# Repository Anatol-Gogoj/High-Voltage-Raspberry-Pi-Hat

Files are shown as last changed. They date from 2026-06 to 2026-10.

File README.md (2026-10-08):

# High Voltage Raspberry Pi Hat
A high voltage Raspberry Pi hat dedicated to controlling and powering Dielectric Elastomer Actuators (DEAs) through a dedicated circuit without the risk of burning out expensive high voltage equipment.

Two channels, up to 5 kV into loads under 1 nF, with independent charge, hold and active
discharge per channel and a passive 1 GOhm bleeder across each output. Rev B fits the standard
65 x 56 mm HAT outline with the HV section potted. KiCad 10 project in
[`HV Pi Hat/`](HV%20Pi%20Hat/); design decisions are in
[`HV Pi Hat/docs/adr/`](HV%20Pi%20Hat/docs/adr/).

**Safety:** this board generates 5 kV. It has not been fabricated or reviewed by a qualified
electrical engineer, and the HV spacing basis is still open (ADR-0003). Do not build or energize
it from this repository as it stands.

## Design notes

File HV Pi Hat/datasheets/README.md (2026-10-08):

# Datasheets — HV Pi Hat

Local copies of datasheets for the key parts in this design. Pulled 2026-06-05.

| Part | Ref(s) | Role | Key specs | File | Source |
|---|---|---|---|---|---|
| HVM SMHV0550 | U1 | 5 kV programmable HV DC-DC module | 0–5 kV out, **200 µA** max, 5 V in (<350 mA), Program 0–5 V, Vmon/Imon 0–1 V, Ilimit (tie 5 V to disable), non-isolated (HVRTN=GND), 45–80 kHz | `HVM_SMHV_series.pdf` | [hvmtech.com/smhv-series](https://www.hvmtech.com/smhv-series) |
| HVM OPTO-100-05 | OR1–OR4 | HV opto-coupler (charge path / HV switch) | **10 kV** standoff, **CTR 0.15%**, LED Vf 2.9–3.25 V, LED 400 mA max, turn-on/off 2 µs, internal current-limit R | `HVM_OPTO-100.pdf` | [hvmtech.com/opto100](https://www.hvmtech.com/opto100) |
| Murata MHR0317SA107F70 | R1, R2 | HV bleeder / discharge resistor | **100 MΩ** (code 107), 0317 size, axial HV chip | `Murata_MHR0317SA_series.pdf` | [murata.com](https://www.murata.com/en-us/products/resistor/highvoltage) |
| Microchip TN0610N3-G | Q1–Q4 | N-MOSFET — opto-LED low-side driver | 100 V, 500 mA, Vgs(th) ≤ 2 V, TO-92 | `TN0610N3-G_Microchip.pdf` | [microchip.com/TN0610](https://www.microchip.com/en-us/product/TN0610) |

## Design notes uncovered while collecting these

1. **R1/R2 value corrected.** Part `MHR0317SA107F70` is **100 MΩ** ("107" = 10×10⁷). The schematic/PCB previously labeled it "50 M" — that label was wrong and has been corrected to "100 M". No part change needed.

2. **OPTO-100 CTR = 0.15% gates the achievable output voltage.** The opto's HV side is a light-controlled photodiode, not a low-impedance switch. Output current Iout ≈ 0.0015 × I_LED. In steady state the channel output settles at V ≈ Iout × R_bleeder (until it nears the 5 kV rail).
   - To reach **5 kV** across a **100 MΩ** bleeder you need Iout ≥ 50 µA → **I_LED ≥ ~33 mA** → opto-LED resistor (R3/R4) ≈ **50–60 Ω**, *not* the present 200 Ω.
   - With the present **200 Ω** (I_LED ≈ 10 mA → Iout ≈ 15 µA) the output is clamped at only **~1.5 kV**. **R3/R4 must be reduced to hit the full voltage** (TBD once final max-V target is set; design is "variable to 5 kV").

   > **Correction (2026-10-08):** the datasheet's "Current Transfer Ratio (Iin vs Iout)" graph is not
   > proportional: output is about 0 at 40 mA LED current and rises 0.15 % above that, so ~38 mA
   > (51 Ω) gives little or no output. Rev B uses 15 Ω (~110 mA); see `docs/adr/0006-opto-led-drive.md`
   > and bench test T1. The 100 MΩ-bleeder argument above predates active discharge: the standing
   > load is now the 1 GΩ bleeder.
3. **SMHV0550 control needs attention:** Program (pin 3) wants a 0–5 V analog level — the Pi has no DAC, so this needs a filtered PWM or an external DAC. Ilimit (pin 7) should be tied to 5 V (disable) or driven 0–1 V. Verify both are wired. Vmon/Imon (0–1 V) can feed an ADC for telemetry.

4. **Input filtering:** the module switches at 45–80 kHz and draws up to ~350 mA pulsed — add input bulk capacitance + an LC/ferrite on its 5 V feed, and budget ~0.5 A total from the Pi 5 V rail (module + 2 opto LEDs + indicators).

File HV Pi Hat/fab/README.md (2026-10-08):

# Fabrication outputs

No Gerbers or drill files are committed, on purpose. This is a 5 kV board, and outputs stay out of
the repo until all of these hold:

1. The ADR-0003 prerequisites are done (IEC 60664-3 Table 1 spacings in the DRC rules, potting
   compound chosen, qualification test defined and passed) and the board passes DRC against them.
2. A qualified human EE has reviewed the schematic and the HV layout, including the through-board
   distances from `tools/HvInterlayer.py`.
3. The order specifies the ADR-0002 stackup (JLCPCB JLC04201H-7628D, 2.0 mm), not the default.

The Gerbers that used to sit in the project root and in `HV Pi Hat.zip` / `.7z` were from the
December 2025 design, which had the bugs listed in `docs/REVIEW_FINDINGS.md`. The
`preliminary_DO_NOT_FAB/` set was from an unroutable June 2026 intermediate. Both were removed on
2026-10-08 and remain in git history.

`BOM.csv` is generated from the schematic (`docs/TOOLING.md`); sourcing is in `docs/BOM_SOURCED.md`.

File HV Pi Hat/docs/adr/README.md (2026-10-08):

# Architecture decision records

One decision per file, numbered in order. A new decision gets a new file; a changed decision gets
a new ADR that supersedes the old one, and the old one's status line points to it.

| ADR | Title | Status |
|---|---|---|
| [0001](0001-baseline-design-decisions.md) | Baseline design decisions (migrated from `DECISIONS.md`) | Accepted; rows partly superseded |
| [0002](0002-hv-on-outer-layers.md) | HV on the outer layers, inner layers voided, thick stackup | Accepted |
| [0003](0003-hv-spacing-basis.md) | HV spacing basis: encapsulate the HV zone | Accepted; prerequisites open |
| [0004](0004-board-footprint.md) | Board footprint: standard HAT outline (65 x 56.0 mm for a THT header) | Accepted; rev B meets it |
| [0005](0005-mechanical-stack.md) | Mechanical stack: 20 mm standoffs, GPIO header, Pi 5 parts underneath | Accepted; header pending bench test T3 |
| [0006](0006-opto-led-drive.md) | Opto LED drive current: 15 Ohm (CTR threshold) | Accepted; pending bench test T1 |
| [0007](0007-hatplus-compliance.md) | HAT+ compliance: ID EEPROM, underside socket, unplated holes | Accepted |

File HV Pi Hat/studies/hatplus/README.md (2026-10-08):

# HAT+ outline placement study (issue #4)

**Question (ADR-0004):** does the 2-channel active-discharge circuit fit the standard 65 x 56.5 mm
HAT+ outline once the HV zone is potted (ADR-0003)?

**Answer:** yes, at the ADR-0003 interim rules. A full placement routes with zero KiCad DRC errors
and zero unconnected items at 2 mm HV spacing, and the same placement still routes cleanly at 3 mm.
This is a feasibility result from a scripted router, not a finished layout (see "Not shown").

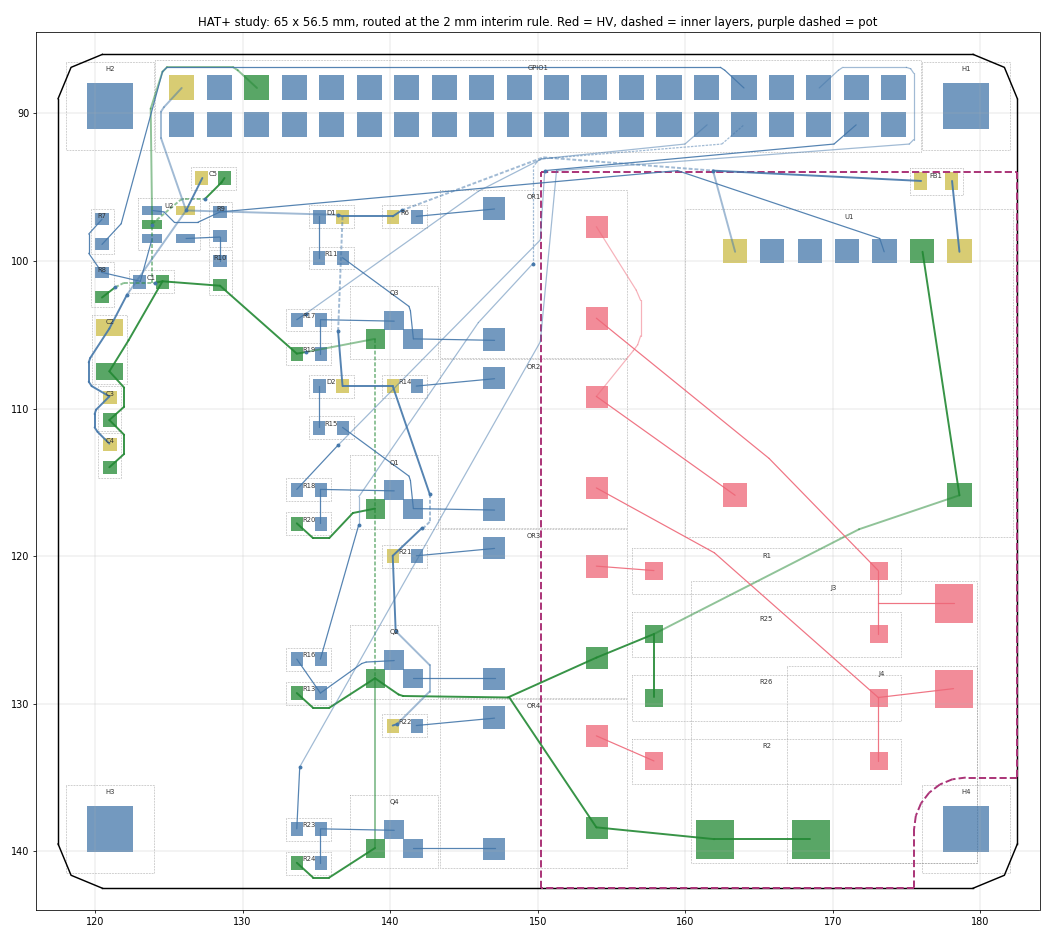
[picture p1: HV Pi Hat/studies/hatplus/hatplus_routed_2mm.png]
Routed at 2 mm


## Setup

- Outline 65 x 56.5 mm with 3 mm corners. The four holes (58 x 49 mm pattern) and the 40-pin header
  stay where rev A had them, which is already the HAT+ position.
- Rules (ADR-0002, ADR-0003 interim): HV copper on F.Cu/B.Cu only; In1/In2 voided under the pot; HV
  copper at least 3 mm inside the pot edge; 2 mm HV clearance (also run at 3 mm); 0.5 mm copper to
  board edge; pot notched around the H4 screw (3.5 mm radius).
- Changes from rev A:
  - J3/J4 screw terminals replaced by soldered-lead pads (2.6 mm pad, 1.3 mm drill). The HV pads sit
    next to the HV resistors; the return pads sit on GND near the bottom edge. ADR-0003 rules out
    terminals inside the pot.
  - U1 rotated so its LV pin row faces the header and HV pin 8 is at its lower-left corner.
  - Optos in one column, LED pins facing the drivers, HV pins facing the HV zone.
  - The four HV resistors stacked under U1.
  - Each MOSFET driver cluster aligned with its opto.
  - +5V bulk caps C2 to C4 moved to the power entry by header pins 2 and 4. They were boxed in when
    placed next to U1, and ADR-0001 only requires them on +5V before the ferrite.

## Results

| | 2 mm interim | 3 mm sensitivity |
|---|---|---|
| Connections routed by the study router | all | all |
| KiCad DRC errors (kicad-cli 10.0.1) | 0 | 0 |
| Unconnected items | 0 | 0 |
| Vias (HV vias) | 21 (0) | 22 (0) |
| Smallest HV copper to pot edge | 3.00 mm | 3.00 mm |
| Smallest HV to non-HV distance through the board (`tools/HvInterlayer.py`) | 2.08 mm, about 2.4 kV/mm at 5 kV | 2.60 mm, about 1.9 kV/mm |
| Pot area | 1516 mm2 per face, 41 % of the board | same |

For comparison, rev A's smallest through-board distance is 1.91 mm.

## Not shown, and open items

1. **Routing quality.** The router proves the nets fit; it does not produce a layout to fabricate.
   A hand pass in pcbnew should take the GPIO lines that still cut across the pot's top-left
   corner out of the pot (they pass HV_RAIL at the 2 mm minimum), pour GND instead of the long GND
   tracks, and fix the silkscreen.
2. **Pot process.** U1's HV pin 8 is under the module body, so the potting has to fill under the
   module, or the module needs standoffs. The qualification test (ADR-0003 prerequisite 3) has to
   cover that spot.
3. **Bottom pot vs the Pi 5.** The THT HV joints put pot on the bottom face too. Its thickness against
   the 16 mm standoff height recommended by HAT+ is not checked; the Pi 5 drawing gives no
   component heights.
4. **Schematic.** Adopting this needs J3/J4 footprints changed to the soldered-lead pads (new
   footprint in `HV_Pi_Hat.pretty`). Everything else is layout only.
5. **ID EEPROM.** Not placed. There is free area on the left (about x 118 to 132, y 115 to 135) near
   ID_SD/ID_SC.
6. **Spacing basis.** 2 mm is the interim rule. The real number comes from IEC 60664-3 Table 1 (ADR-0003
   prerequisite 1); the 3 mm run shows the placement has headroom.

## Reproduce

From this directory, with the KiCad 10 python (`/c/Program Files/KiCad/10.0/bin/python.exe`):

    python StudyBoard.py "../../HV Pi Hat.kicad_pcb"    # rev A board -> hatplus.kicad_pcb, placed
    python AutoRoute.py hatplus.kicad_pcb 2.0            # route at 2 mm (use a copy with a 3 mm .kicad_dru for 3.0)
    kicad-cli pcb drc --severity-all --format json -o drc_hatplus.json hatplus.kicad_pcb
    python ../../tools/HvInterlayer.py hatplus.kicad_pcb
    python ../../tools/PotMargin.py hatplus.kicad_pcb

`Layout.py` holds the placement. `hatplus.kicad_pro` and `hatplus.kicad_dru` are copies of the main
project's, so the netclasses and HV rules resolve. Footprint-library warnings in DRC are expected
here: the study folder has no library tables.

## Suggested next step

Promote this placement to the main board as rev B: add the soldered-lead footprint and update J3/J4
in the schematic, apply `Layout.py` to the main board, route, then do the hand pass from item 1 and
re-run DRC, `tools/HvInterlayer.py` and `tools/PotMargin.py`.

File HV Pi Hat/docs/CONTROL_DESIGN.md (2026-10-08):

# HV Pi Hat — corrected control/drive design (to implement)

Resolves `REVIEW_FINDINGS.md`. Decisions locked 2026-06-05:
PGM = RC-filtered PWM + op-amp ×1.55 (full 5 kV) · ILIMIT tied to 5 V ·
indicators = **parallel** branches off each MOSFET · **active charge AND discharge**
(separate opto per direction) · high-value always-on safety bleeder (DNP-able).

## Per-channel block (×2)
```
        SMHV HVOUT (rail, shared by both channels)
          │
   [OR_chg] HVIN→HVOUT ──┬──────────────┬───────── J pin2 (HV+) → DEA(+)
                         │              │
                    R_dis 100M     R_safety 1G (populated, always-on fail-safe)
                         │              │
                  [OR_dis] HVIN         │
                  [OR_dis] HVOUT ───────┴──── GND ;  J pin1 → GND → DEA(−)

 Charge drive:    +5V ┬ R_opto_chg 15Ω ─ OR_chg LED(+→−) ┐
                      └ R_ind 470Ω ─ D_chg(A→K) ─────────┴ Q_chg DRAIN
                                       Q_chg SRC ─ GND ;  GATE ← GPIO_chg (100Ω series, 10k→GND)
 Discharge drive: +5V ┬ R_opto_dis 15Ω ─ OR_dis LED(+→−) ┐
                      └ (opt) R_ind2 470Ω ─ D_dis ────────┴ Q_dis DRAIN
                                       Q_dis SRC ─ GND ;  GATE ← GPIO_dis (100Ω series, 10k→GND)
```
- **Charge:** assert GPIO_chg → OR_chg conducts → DEA charges toward the rail (set by PGM).
- **Hold:** both optos off → DEA holds (slow bleed only through R_safety).
- **Discharge:** assert GPIO_dis → OR_dis conducts → DEA dumps through R_dis to GND.
- `R_dis` 100 MΩ → ~100 ms dump for <1 nF; drop to ~10 MΩ for a faster (~10 ms, opto-limited) dump.
- `R_safety` ~1 GΩ (Murata MHR0317SA108F70) → τ≈1 s; fail-safe bleed when unpowered. Populated by default; DNP only if a passive bleed is unwanted (finding F-9).
- Opto = HVM OPTO-100 (10 kV, CTR 0.15% incremental above a ~40 mA threshold per the datasheet graph); `R_opto_*` **15 Ω 1206** → I_LED ≈ 110 mA → Iout ≈ 90–110 µA (ADR-0006). The old 51 Ω gave ~38 mA, at the threshold. The only standing output load is the 1 GΩ bleeder (5 µA at 5 kV); Iout sets the charge/discharge speed (~50 ms per 0–5 kV edge at 1 nF).

## Shared: HV setpoint (PGM) — full 0–5 kV
```
GPIO12/PWM0 ─ R 10k ─┬──────────┬─ V+ op-amp (RRIO, 5V; e.g. MCP6001)
                     C 1µF      R 100k          OUT ─────────── SMHV PGM (pin3)   (opt: 100nF PGM→GND)
                     │          │   feedback: Rf 5.6k (OUT→V−), Rg 10k (V−→GND) ⇒ gain 1.55
                    GND        GND
```
- 100k pulldown ⇒ PGM=0 (HV off) at boot. RC corner ≈16 Hz; run PWM ≥20 kHz. Op-amp: 0.1 µF decoupling.

## Shared: SMHV module
- VIN(1)=+5V with **47 µF + 1 µF + 0.1 µF** bulk/decoupling; ferrite bead from Pi 5 V → module 5 V.
- GND(2), HVRTN(9) = GND.  **ILIMIT(7) → 5 V** (full output).  PGM(3) ← op-amp.  Vmon/Imon(5/6) → ADC (optional).
- HVOUT(8) = rail → OR_chg HVIN of both channels.

## GPIO map
| Function | GPIO | Pin |
|---|---|---|
| HV setpoint (PGM) | GPIO12/PWM0 | 32 |
| Ch1 charge | GPIO5 | 29 |
| Ch1 discharge | GPIO6 | 31 |
| Ch2 charge | GPIO26 | 37 |
| Ch2 discharge | GPIO16 | 36 |

## BOM vs. current
Add: 2× OPTO-100 (discharge), 2× TN0610 (discharge), 2× 51Ω + 2× 100Ω + 2× 10k (discharge driver),
1× op-amp + RC/feedback/decoupling, 2× R_safety 1GΩ (populated). Reuse R1/R2 (100 MΩ) as R_dis.
Change: R3/R4 200→51Ω (opto charge), R5/R6 300→470Ω (indicator). Optional: 2× discharge indicators.

## HAT+ ID EEPROM (ADR-0007)
U3 CAT24C32 on ID_SD/ID_SC (header pins 27/28), A0..A2 = GND (address 0x50, Standard class), R27/R28 3.9 kΩ pull-ups to +3V3 (header pin 1), WP pulled up by R29 1 kΩ with test point TP1 (drive low to program), C6 100 nF. Nothing else may connect to ID_SD/ID_SC (HAT+ spec ch. 2).

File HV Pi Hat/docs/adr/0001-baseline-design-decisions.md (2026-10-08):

# ADR-0001: Baseline design decisions

- Status: Accepted (2026-06-05 to 2026-06-07); some rows superseded, see the Status column
- Deciders: Anatol Gogoj
- Migrated from `docs/DECISIONS.md` on 2026-10-08. Full rationale for the 2026-06-07 rows is in
  `docs/AUTONOMOUS_BUILD_LOG.md`.

## Context

The original December 2025 schematic had functional bugs (floating `ILIMIT`, opto-LED resistors
too large to reach 5 kV, an indicator stack that starved the opto). `docs/REVIEW_FINDINGS.md`
records them. The decisions below fixed the circuit and set the board-level constraints.

## Decisions: circuit and board (2026-06-05)

| Area | Decision | Why | Status |
|---|---|---|---|
| Form factor | 85 x 56 mm, wider than the 65 mm HAT | Room for 5 kV creepage | Superseded by ADR-0004 (target the standard HAT+ outline) |
| Insulation | Conformal coat as baseline; pot or encapsulate if more margin is needed | Lets 5 kV fit a small board | Current |
| HV spacing | 4 mm clearance, creepage and edge on HV nets, milled slots between polarities | Coated 5 kV figure | Superseded by ADR-0003. Slots were not used: KiCad treats slot edges as board edge, which conflicts with the HV-to-edge rule |
| Max voltage | Hardware headroom to 5 kV; run lower in firmware | | Current. The build log puts the true ceiling at about 4.68 kV from a 3.3 V PWM through the x1.56 stage |
| DEA load | Less than 1 nF | Charge and discharge both fast | Current |
| Discharge resistor | 100 MOhm (R1, R2, Murata MHR0317SA107F70) | Two-channel 200 uA budget | Current, reused as `R_dis` |
| HV output connector | 2-position terminal block per channel with a slot between pads | | Superseded twice; see the connector row below |
| HV setpoint (PGM) | PWM, RC filter, MCP6001 op-amp x1.55, module PGM | Pi has no DAC; 3.3 V PWM alone caps near 3.3 kV | Current |
| Current limit | `ILIMIT` (pin 7) tied to 5 V | Module is inherently 200 uA | Current |
| Indicators | Kept, as a parallel branch off each channel MOSFET | A series stack starved the opto | Current |
| Discharge | Active: second opto plus series R per channel | Independent charge, hold, discharge | Current |
| Safety bleeder | 1 GOhm always on across each output, DNP-able | Fail-safe bleed-down when unpowered | Current. Populated by default (finding F-9) |

## Decisions: autonomous build pass (2026-06-07)

| Area | Decision | Why | Status |
|---|---|---|---|
| Indicator branch | +5V, R (470 Ohm), LED, MOSFET drain | The opto-LED node left about 0.1 V headroom; the drain node gives about 6 mA | Current |
| Input bulk caps | Keep 47/1/0.1 uF on +5V; add C5 0.1 uF op-amp decoupling | A ferrite is nearly transparent at the module's 45 to 80 kHz switching | Current |
| Custom symbol pin types | MOSFET SRC/DRAIN, opto pins, module HVRTN set to passive; ILIMIT set to input | Cleared false output-to-output ERC errors | Current |
| Power flags | PWR_FLAG on +5V and GND | Board is powered from the Pi | Current |
| HV netclass binding | `.kicad_pro` pattern `/HV_*` maps to `HV_5kV` | Survives net renames | Current |
| Passive footprints | 0603 for the 51 Ohm opto-LED resistors and other passives; 1206 for 47 uF | Power margin and hand soldering | Opto-LED resistors superseded by ADR-0006 (15 Ohm, 1206) |
| HV output connector | 1x2 screw terminal, 10.16 mm pitch (`TerminalBlock_RND_205-00241`), pad 1 = GND, pad 2 = HV out | SHV-R rejected: about 34 mm footprint and only 3.5 kV continuous | Current on the board. The part choice and the soldered-lead alternative are in `docs/HV_CONNECTOR_OPTIONS.md` and are tied to ADR-0004 |

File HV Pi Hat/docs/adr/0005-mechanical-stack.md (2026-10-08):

# ADR-0005: Mechanical stack: standoff height, GPIO header, and the Pi 5 parts underneath

- Status: Accepted 2026-10-08 (Anatol): 20 mm standoffs.
- Deciders: Anatol Gogoj
- Related: ADR-0003 (bottom-face pot), ADR-0004 (HAT outline)

## Context

The HV zone is potted on both faces (ADR-0003), so the HAT's underside carries THT lead tails and a
pot over the right part of the board. What sits below it on a Raspberry Pi 5 was checked against the
official drawings (Pi 5 mechanical drawing RP-008347-DS-1, Active Cooler drawing RP-008187-DS-1,
HAT+ spec RP-008281-DS-1) and run through `tools/revb/PiKeepouts.py`. Assumptions: leads trimmed to
1.5 mm, bottom pot 3.0 mm thick.

| Pi 5 part | Under the HAT? | Height above Pi PCB | Room at 16 mm | Room at 20 mm |
|---|---|---|---|---|
| Active Cooler (fan directly under the pot) | yes, almost the whole board | 13.70 overall (drawing; pin tip to cap top) | **-0.7 mm** | 3.3 mm |
| PoE 2x2 header | yes, under the pot | 8.6 | 4.4 mm | 8.4 mm |
| Camera/display FPC connectors | yes, under the HV resistors | 4.1 | 8.9 mm | 12.9 mm |
| UART, RTC battery, PCIe FFC | yes | 4.2 to 4.5 | 8.6 mm or more | 12.6 mm or more |
| USB-A stacks, RJ45, fan connector | no: they start 5.7, 1.8 and 0.2 mm beyond the 65 mm edge | 15.9 / 14.0 / 4.5 | n/a | n/a |

The 13.70 mm cooler figure runs from the push-pin tip (below the Pi PCB) to the top of the pin cap,
so the real height above the PCB is lower; how much lower is not published.

The HAT+ spec (ch. 7) says: "provide at least 15mm board-to-board spacers; 16mm spacers are ideal. If
the underside of your HAT+ has components on it, use even larger spacers." It also says a HAT+
"should not interfere with access to camera, display, and PCIe flex connectors" (a recommendation).

The BOM's GPIO socket, Sullins PPTC202LFBN-RC, has an 8.51 mm body (DigiKey attributes; Sullins
series datasheet 0.335 in). On its own it cannot produce a 16 or 20 mm board-to-board gap, so the
header has to be re-specified whatever the standoff decision is.

## Options

1. **16 mm standoffs** (HAT+ default). Works only if the measured cooler top is 12.0 mm or less above
   the Pi PCB (16 - 3.0 pot - 1.0 margin).
2. **20 mm standoffs** with a GPIO stacking header to match. Clears the worst-case cooler by 3.3 mm,
   and follows the spec's advice for HATs with underside components.
3. **Passive heatsink instead of the Active Cooler** (the case heatsink is 4 mm). Clears easily at
   16 mm, at the cost of CPU cooling headroom.

## Decision

Option 2: **20 mm board-to-board standoffs**, with a GPIO header stack chosen to give exactly that gap.
This clears the worst-case Active Cooler height by 3.3 mm without needing the bench measurement, and
follows the HAT+ spec's advice to use larger spacers when the HAT has underside components. It
deviates from the spec's 16 mm "ideal"; the spec allows it.

## Consequences

- The GPIO header must be re-specified for a 20 mm gap (the PPTC202LFBN-RC gives about 11 mm).
  Proposed: **Samtec ESQ-120-14-G-D** elevated socket (11.05 mm insulator, 12.19 mm tails, DigiKey
  attributes). It is seated on the Pi's pins with its tails up through the HAT, and soldered with the
  HAT already on its 20 mm standoffs, so the standoffs alone set the height. The tail tip lands
  h_b + 23.24 mm above the Pi PCB (h_b = top of the Pi header's plastic base), always above the
  HAT top at 22.0 mm; trim to about 1.5 mm after soldering. Pin engagement is the Pi pin length
  above its base (h_p - h_b) and must be at least 3.68 mm (Samtec insertion range, read from
  secondhand copies of the datasheet). The Pi 5 drawing gives neither h_b nor h_p: measure both on
  the bench Pi before ordering. Raspberry Pi's 16 mm stacking header and the 13.5 mm tall
  sockets under-engage at 20 mm.
- GPIO1 is now a bottom-side 2x20 socket footprint (ADR-0007), pad positions unchanged, value
  "Samtec ESQ-120-14-G-D" pending bench test T3.
- The fan intake faces up and sits under the pot with 3.3 mm of room in the worst case (more if the
  cooler is lower than its 13.70 mm overall figure). Whether that costs enough cooling to matter is
  unknown; check SoC temperature under load with the HAT fitted.
- Camera/display flex access with the HAT fitted is not provided: those connectors sit under the HV
  resistor block, which a cutout like the M.2 HAT+'s would destroy. The left edge is kept free of
  parts and copper (`PcieNotch` in `tools/revb/RevBLayout.py`) so a PCIe flex notch stays possible.

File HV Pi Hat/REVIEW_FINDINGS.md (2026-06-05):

# HV Pi Hat — design review findings (2026-06-05)

Source: KiCad netlist + datasheets (see `datasheets/`). Architecture concept is sound
(SMHV0550 5 kV/200 µA module → per-channel OPTO-100 photo-coupler as charge switch →
DEA, with a bleeder for discharge, MOSFET driving the opto LED, optical control isolation).
But as wired the control/drive path will **not** produce useful HV. Issues below, by priority.

## As-wired drive path (per channel)
`+5V → R6/R5 (300Ω) → D1/D3 (indicator LED) → R3/R4 (200Ω) → OPTO LED → Q1/Q2 (low-side, GPIO gate) → GND`
`SMHV HVOUT (rail) → OPTO photodiode → DEA(+) [J3/J4 pin2];  DEA(−)[pin1] → R1/R2 (100MΩ) → GND`

## Critical

**A. SMHV `ILIMIT` (pin 7) is floating.** Datasheet: pin 7 is the current-limit *input*
(0–1 V → 0–100 % of rated current; **tie to 5 V to disable**). Floating ≈ 0 V ⇒ ~0 % limit
⇒ module sources ~no current. → **Tie pin 7 to 5 V** (disable) or to a divider for a set limit.

**B. Opto LED is starved.** With the indicator LED *in series* and R=500 Ω total, the drop is
~2 V (D1) + ~2.9 V (opto LED) ≈ 4.9 V of the 5 V rail → only ~0.2 mA through the opto LED.
At CTR 0.15 % that's ~0.3 µA out → < ~50 V at the output. Even without the indicator (500 Ω),
only ~4 mA → ~6 µA → < ~0.7 kV.
→ **Remove the indicator from the series path** and **drop the opto-LED resistor to ~60 Ω**
(I_LED ≈ 33 mA → Iout ≈ 50 µA → can drive 100 MΩ to 5 kV). Size: R ≈ (5 − 2.9)/I_LED.

**C. Bleeder R1/R2 is in the wrong leg.** It sits between the DEA return pin and GND (in series
with the actuator), so the HV+ node has **no discharge path** when the opto is off — no actuator
relaxation and **no bleed-down safety**. → **Re-wire R1/R2 across the HV output** (HV+ node → GND),
and tie the DEA return pin directly to GND. Then τ = R·C = 100 MΩ × <1 nF ≈ <100 ms.

## Major

**D. PGM control is a raw 3.3 V PWM, unfiltered.** SMHV `PGM` (pin 3) wants 0–5 V analog
(0–5 V → 0–full scale). It's driven straight from GPIO12/PWM0 with no RC filter.
- No filter ⇒ the module sees a square wave (ripple/instability on HV out).
- 3.3 V max ⇒ only ~66 % of full scale ⇒ **~3.3 kV ceiling** even if filtered.
→ Add an RC low-pass (e.g. 10 kΩ + 1 µF). For the **full 5 kV**, add a 3.3 V→5 V gain stage
(rail-to-rail op-amp ×~1.55 from 5 V) **or** use an I²C DAC (e.g. MCP4725) at 5 V for clean analog.

## Housekeeping

- **Decoupling / bulk:** none present. Add input bulk cap at SMHV Vin (it switches 45–80 kHz,
  draws up to ~350 mA) + local decoupling; budget ~0.5 A from Pi 5 V (module + 2 opto LEDs).
- **Ch-1 enable uses GPIO1/ID_SC (pin 28)** — a HAT-ID-EEPROM pin. Move to a normal GPIO.
- **Vmon/Imon (pins 5/6) unconnected** — optional: route to an ADC for telemetry.

## GPIO map (current)
| Function | GPIO | Pin |
|---|---|---|
| SMHV PGM (HV setpoint) | GPIO12 / PWM0 | 32 |
| Ch1 enable (Q1 gate) | GPIO1 / ID_SC ⚠ | 28 |
| Ch2 enable (Q2 gate) | GPIO26 | 37 |

## Decisions pending
1. Full 5 kV (adds PGM level-shift/DAC + opto-LED R sized for 5 kV) vs accept ~3 kV (RC filter only)?
2. Current limit: disable (tie 5 V) vs set a protective limit (divider on pin 7)?
3. Keep per-channel indicator LEDs (moved onto the enable GPIO) or drop them?

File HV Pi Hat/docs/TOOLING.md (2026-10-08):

# Tooling: HV Pi Hat

- **kicad-cli:** `/c/Program Files/KiCad/10.0/bin/kicad-cli.exe` (10.0.1 verified 2026-10-08)
- **KiCad Python (has `pcbnew`):** `/c/Program Files/KiCad/10.0/bin/python.exe`
- The project is KiCad 10 format. The 9.0 CLI cannot load the schematic.
- Run commands from the project dir (parent of `docs/`); files: `HV Pi Hat.kicad_pcb` / `.kicad_sch`.

## DRC (honors the custom HV rules in `HV Pi Hat.kicad_dru`)
    kicad-cli pcb drc --format json --severity-all --schematic-parity \
      --output drc.json "HV Pi Hat.kicad_pcb"
Use kicad-cli, not `pcbnew.WriteDRCReport`, which asserts ("process failed") outside the GUI.
HV rule violations show up as `clearance`, `creepage`, `copper_edge_clearance`, `hole_clearance`.

## ERC
    kicad-cli sch erc --format json --severity-all --output erc.json "HV Pi Hat.kicad_sch"

## BOM
    kicad-cli sch export bom --fields "Reference,Value,Footprint,QUANTITY,DNP" \
      --labels "Reference,Value,Footprint,QUANTITY,DNP" --group-by "Value,Footprint" \
      --ref-range-delimiter "" -o fab/BOM.csv "HV Pi Hat.kicad_sch"

## Render (PNG)
    kicad-cli pcb render --side top --quality basic --width 1600 --height 1100 -o render_top.png "HV Pi Hat.kicad_pcb"

## Netlist (read connectivity without the GUI)
    kicad-cli sch export netlist -o net.net "HV Pi Hat.kicad_sch"
Fails to load while the `.sch` is open in eeschema; close eeschema first.

## HV interlayer check (what the 2-D DRC cannot see)
    "/c/Program Files/KiCad/10.0/bin/python.exe" tools/HvInterlayer.py "HV Pi Hat.kicad_pcb"
Prints the smallest 3-D distances between HV copper and non-HV copper on other layers, using the
ADR-0002 stackup, and the average field at 5 kV. Re-run after any HV re-route or stackup change.
Round pads use their true radius; other pads their circumscribed circle (conservative).

## pcbnew scripting gotchas (KiCad 10.0.1)
- **Load boards from inside the project directory.** Zone fill and netclass lookup need the
  `.kicad_pro` and `.kicad_dru` next to the board. A board loaded from elsewhere fills GND right up
  to the HV copper with default clearances and reports every net as `Default`.
- `GetEffectiveNetClass()` returns an unwrapped SWIG object. Use `GetNetClassName()`, which can be
  a composite such as `"HV_5kV,Default"`; take the strictest member.
- `Board.Remove(item)` can break SWIG typing for later `GetTracks()` / `GetFootprints()` calls
  (symptom: "memory leak of type 'PCB_TRACK *'", then `SwigPyObject` has no attribute ...). Collect
  UUIDs read-only and delete the `(segment ...)` blocks from the file text instead.
- `pcbnew.FromMM()` rejects numpy floats; cast with `float()`.
- The board file is CRLF on Windows. Text edits must preserve the newline style.
- After any change that touches GND copper, check that GND is one connected network
  (`kicad-cli pcb drc` reports 0 unconnected items). Pour islands are kept when they hold a pad,
  so a cut-off island shows up only as an unconnected zone-to-zone item.

## Footprint save to a project `.pretty`
Use the IO manager. KiCad 10 renamed `PluginFind` (9.0) to `FindPlugin`:

    import pcbnew
    io = pcbnew.PCB_IO_MGR.FindPlugin(pcbnew.PCB_IO_MGR.KICAD_SEXP)
    io.FootprintSave(pretty_dir, footprint)

`tools/MakeLeadPair.py` is a working example. Library nickname for the project footprints is
`HV_Footprints` (it points at `HV_Pi_Hat.pretty`); there is no `HV_Pi_Hat` nickname.

## Rev B build (HAT+ outline)
    "/c/Program Files/KiCad/10.0/bin/python.exe" tools/revb/BuildRevB.py
    "/c/Program Files/KiCad/10.0/bin/python.exe" tools/revb/AutoRoute.py "HV Pi Hat.kicad_pcb" 2.0
BuildRevB rewrites the board in place with the placement in `tools/revb/RevBLayout.py` (it strips and
rebuilds, so it runs on rev A or on an existing rev B);
AutoRoute routes it (HV first, LV kept out of the pot) and pours GND. Then run DRC with
`--schematic-parity`, `tools/HvInterlayer.py` and `tools/PotMargin.py`.

## Pi 5 parts under the HAT
    "/c/Program Files/KiCad/10.0/bin/python.exe" tools/revb/PiKeepouts.py "HV Pi Hat.kicad_pcb" --standoff 16 [--draw]
Reports the room between each Pi 5 part (`RevBLayout.Pi5Parts`) and the HAT underside; `--draw`
adds the outlines to User.2. See ADR-0005.

## Pot margin
    "/c/Program Files/KiCad/10.0/bin/python.exe" tools/PotMargin.py "HV Pi Hat.kicad_pcb"
Smallest distance from HV copper to the pot edge (the `PotVoid_In1.Cu` rule area); ADR-0003 wants 3 mm.

## Limitations (drives who-does-what)
- **No schematic Python API**, so schematic edits are eeschema **GUI** (or risky text surgery).
- **"Update PCB from Schematic"** (forward annotation) is GUI-only, not in kicad-cli.
- The **PCB is fully scriptable** via `pcbnew` (placement, tracks, zones, footprints).
- Freerouting does not handle the HV zone (about 4 minutes per pass, no clean result). HV was
  routed by script.

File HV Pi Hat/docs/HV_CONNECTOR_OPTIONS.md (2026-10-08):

# HV Output Connector Options — 5 kV DEA-Driver Pi HAT (J3, J4)

**Date:** 2026-06-07
**Board:** 85 x 56 mm 2-channel HAT, output up to 5 kV (run ~4.7 kV max), HV+ and HV- (= board GND/return) per channel, load < 1 nF.
**Distributor preference:** DigiKey, Mouser OK.
**Replaces:** Tyclon **SHV-R** (DigiKey 4912-SHV-R-ND) — rejected: ~34 mm footprint and only **3.5 kV continuous** (5 kV is 1-min withstand only). Interim part is a generic 1x2 screw block.

> **Pricing/stock note:** DigiKey product pages block automated reads (HTTP 403), so unit prices below come from mirror distributors / search snippets and should be confirmed at cart. Stock is approximate as of the date above.

---

## The key engineering point first: this is a *creepage/clearance* problem, not a "buy a 5 kV connector" problem

There is no cheap, small, **truly 5 kV-continuous-rated, board-mount** 2-pin connector. The honest options split three ways:

1. **A coarse-pitch screw terminal** whose geometry gives the creepage (the connector's own *printed* voltage rating is ~1 kV — that number is a UL/IEC pollution-degree-2 spacing rating for the **terminal's own internal** clearances, not a ceiling on what you can run pole-to-pole if you space the poles out and coat the board). The 10.16 mm pitch + large insulating body is what buys the margin.
2. **A genuine HV coax jack** (SHV/MHV). Done "right" (Radiall / Huber+Suhner) these are 5 kV-continuous-plus, but they are panel-mount, ~$25-45, and ~25-34 mm — i.e. the thing you're trying to get away from. Board-mount SHV PCB jacks exist but cap at **3.5 kV continuous**, same trap as the Tyclon.
3. **Directly soldered HV silicone lead + strain relief.** Often the *most* reliable 5 kV termination and the cheapest. No mating connector = no creepage path across a connector body, no contact-resistance hot spots.

**Creepage target (IEC 60664-1):** for ~5 kV working voltage at **pollution degree 2**, required creepage is roughly **9-14 mm** depending on CTI material group; at **pollution degree 1** (achieved by a qualifying conformal coating + sealed enclosure) it drops to roughly **clearance-limited ~5-6 mm**. Your board already runs **4 mm clearance + creepage with conformal coat** on HV nets and a custom DRU. A **10.16 mm-pitch** block gives ~10 mm pole-to-pole creepage on its own — comfortably in range with the coating, and it's the smallest standard pitch that does. **7.62 mm (~7.6 mm creepage) is marginal — only acceptable coated and with a slot/conformal coat;** do not use it bare. Below 7.62 mm: no.

> **Correction (2026-10-08):** the creepage figures in the paragraph above are not supported by the
> standard. IEC 60664-1:2020 Table F.5 gives 20 mm at 5000 V for pollution degree 1 and 50 mm for
> pollution degree 2, material group IIIa/IIIb. The board's spacing basis is open; see
> `adr/0003-hv-spacing-basis.md`. On a coat-only basis a 10.16 mm terminal does not meet 20 mm
> pole to pole by itself, which strengthens the case for the soldered lead ranked first below.

---

## Category 1 — HV-capable 2-position screw terminal blocks (the interim direction, done properly)

The realistic, in-stock, cheap winner. Use **10.16 mm pitch** for genuine 5 kV creepage margin. Both parts below are mainstream, stocked, and have ready KiCad footprints.

| # | Mfr + MPN | DigiKey / Mouser PN | Voltage rating (working) | Mount | Pitch / size | In stock? | ~Price (qty 1) | Pro / Con |
|---|---|---|---|---|---|---|---|---|
| 1A | **Phoenix Contact MKDS 5/2-9,5** (or MKDS 5/ 2-10,16) | DK **277-1248-ND** (9.5 mm) | 1000 V (IEC III/2), 6 kV impulse | THT screw, board | 9.5-10.16 mm, ~17 mm body H | Y, high | ~$2.50 | Pro: rugged, ~9.5-10 mm creepage, trivially sourced. Con: 9.5 mm slightly under ideal — prefer the 10.16 mm sibling. |
| 1B | **Phoenix Contact MKDS 10 HV/ 2-ZB-10,16** (1709681) | DK **277-1685-ND** (verify) | 1000 V (IEC III/2), **6 kV impulse**, CTI 600 (PA body) | THT screw, board | **10.16 mm**, large frame (16 mm² / 76 A) | Y | ~$4-6 | Pro: biggest insulating body + 10.16 mm creepage; "HV" frame, CTI 600 → best geometric margin of the cheap blocks. **KiCad footprint on SnapMagic.** Con: physically tall/bulky (it's really a high-*current* block); overkill conductor size. |
| 1C | **Weidmüller LU 10.16/2** (e.g. 1nnn-series, 2-pole, 10.16 mm) | Mouser 651-/ DK 281-series (verify exact 2-pole 10.16) | 1000 V (IEC), CTI per series | THT screw, board | **10.16 mm** | Y | ~$3-4 | Pro: 10.16 mm pitch, KiCad footprints on SnapMagic. Con: confirm the exact 2-position 10.16 mm orderable PN — Weidmüller's LU naming is dense. |

**What pitch gives real 5 kV margin?** **10.16 mm** (~10 mm creepage) is the sweet spot — first standard pitch that meets ~5 kV PD2 creepage outright, and with your conformal coat (effectively PD1) it has large margin. **12.7 mm** (e.g. MKDS 10 HV/2-12,7) buys even more if board area allows. **7.62 mm** is borderline (coated only). **5.08 mm and below: not for 5 kV.**

> Caveat on the "1000 V" label: that's the connector's rated insulation voltage for its *own* internal geometry under standard pollution. You are not certifying the connector to 5 kV — you are using its **pitch and body as the creepage spacer** between two of your own pads and relying on your board's coating/clearance regime for the rest. This is standard practice for one-off / lab HV gear but is **not** a safety-agency-rated 5 kV termination. For a product you'd want a purpose-built HV connector (Category 2) or potting.

---

## Category 2 — Board/panel-mount HV jacks/receptacles (genuine >= 5 kV rated)

| # | Mfr + MPN | DigiKey / Mouser PN | Voltage rating (working) | Mount | Size | In stock? | ~Price | Pro / Con |
|---|---|---|---|---|---|---|---|---|
| 2A | **Radiall R317580000** (SHV bulkhead recept.) | DK **R317580000** (10521497) | **3.5 kV** operating (mated pair 12 kVDC withstand) | Panel/bulkhead, solder cup | ~25 mm + bayonet | Y, ~368 | ~$31 | Pro: rugged, mated pair 12 kV withstand. Con: **operating spec is 3.5 kV** — same continuous-rating trap as Tyclon; big; pricey; not board-mount. **Not better than the rejected part for *continuous* 5 kV.** |
| 2B | **JAW-DROPPER SVJ-05L** SHV jack, right-angle **PCB mount** | (no DK/Mouser PN — direct/antenna-connector.com) | **3.5 kV rms working**, 5 kV withstand | **PCB, right-angle** | small SHV | Direct order only | n/a (quote) | Pro: actually a *board-mount* SHV (rare). Con: 3.5 kV working again; no DigiKey/Mouser stock; lead time/quote. |
| 2C | **Amphenol RF MHV recept.** (e.g. 000-27000) | DK **000-27000** (2643385) | **5 kV DC** (MHV class) | Panel, solder cup | MHV body | Y | ~$15-25 | Pro: MHV is the 5 kV-class coax std; cheaper than Radiall. Con: panel/solder-cup not board-mount; MHV "5 kV" is a class figure — confirm the specific PN's *continuous* number; recessed-pin MHV is less finger-safe than SHV. |
| 2D | **Huber+Suhner SHV** (11 SHV-50-x series) | Mouser H+S SHV series | SHV class (3.5 kV rms / 5 kV DC typ.) | Panel/bulkhead | SHV | Y (Mouser) | ~$25-40 | Pro: top build quality. Con: still SHV-class continuous limits; panel-mount; pricey. |

**Verdict on Category 2:** none of the *board-mount* HV jacks beat the rejected Tyclon on the thing that mattered (continuous rating) — they're all ~3.5 kV working. The only ones that genuinely exceed 5 kV continuous (Radiall/H+S high-V, true 5 kV MHV) are **panel-mount and as big/expensive as what you rejected.** A smaller-and-cheaper-than-Radiall *and* truly >5 kV board-mount jack **does not appear to exist in DigiKey/Mouser stock today.** If you want a real connector, the right move is a **panel-mount MHV (5 kV) or HV banana wired to the PCB**, not a board jack.

> Standard 4 mm "safety banana" sockets (Stäubli SLB4 etc.) are CAT-rated ~**1 kV** and are **NOT** usable at 5 kV — ruled out.

---

## Category 3 — Wire-to-board HV (often the most reliable 5 kV approach)

| # | Approach | Parts | Voltage | Mount | In stock? | ~Price | Pro / Con |
|---|---|---|---|---|---|---|---|
| 3A | **Direct-solder HV silicone lead + PCB strain relief** | HV silicone wire **5-10 kV** (e.g. 18-20 AWG, 10 kV silicone test-lead wire, DK "silicone wire test leads" partgroup 29052) soldered to a plated HV pad/turret; strain-relieve with a coated zip-tie anchor or potted blob | **5-10 kV** (wire-limited) | Solder to pad/turret | Y (wire is commodity) | ~$1-3/ft + ~$0.30 turret | **Most reliable 5 kV termination.** No mating-connector creepage path, no contact resistance, smallest footprint, cheapest. Con: not field-detachable; needs strain relief + coating; user must solder. |
| 3B | **Keystone HV turret/standoff terminal** (solder post) | Keystone turret terminals (DK Keystone partgroup 23324), e.g. 1502-2 series; or a single large solder pad | post rating high; **creepage set by your spacing** | THT solder post | Y, high | ~$0.20-0.50 | Pro: clean wire anchor, cheap, KiCad footprints exist (TestPoint/Connector libs). Con: bare metal post — must coat/space the two posts >=10 mm apart; not insulated. |
| 3C | **HV silicone lead + ferrule into the interim screw block** | crimp ferrule (e.g. 20-18 AWG insulated ferrule) on 5-10 kV silicone lead, into a 10.16 mm block (1B/1C) | wire 5-10 kV; junction per block geometry | screw block | Y | ~$0.10/ferrule | Pro: keeps a detachable screw interface but with proper HV wire + clean termination. Con: still relies on block geometry for creepage (see Cat 1). |

HV silicone wire is genuinely rated **5, 10, 15 kV+** (stranded tinned Cu, silicone jacket, 200 °C) and is the correct conductor regardless of which termination you pick — **do not run bare hookup wire or standard PVC at 4.7 kV.**

---

## TOP RECOMMENDATION

For this 2-channel, 5 kV, 85 x 56 mm board, ranked:

1. **Primary (lab / current build): Direct-soldered HV silicone lead (Cat 3A) into a plated HV pad with a Keystone turret (Cat 3B) for strain relief.**
   Cheapest, smallest, highest-reliability 5 kV termination; no connector creepage path; matches your existing 4 mm-clearance + conformal-coat HV regime. Use **>=10 kV silicone wire**, anchor + coat the joint, keep the two posts/pads >= 10 mm apart. This is the right answer for a one-off DEA driver.

2. **If you want a re-matable screw interface: Phoenix Contact MKDS 10 HV/ 2-ZB-10,16 (1709681), 10.16 mm pitch (Cat 1B).**
   In-stock, ~$5, ~10 mm pole-to-pole creepage, CTI-600 body, **KiCad footprint available on SnapMagic** (search "MKDS 10 HV/ 2-ZB-10 16"). Terminate the silicone HV lead with a ferrule. This is the proper upgrade from your generic 1x2 block. (MKDS 5/2-9,5 is the smaller fallback if board space is tight, but 9.5 mm is the floor — prefer 10.16 mm.)

3. **Only if a genuine HV *connector* is a hard requirement: panel-mount 5 kV MHV (Amphenol 000-27000, Cat 2C) or Radiall SHV high-V, wired to the PCB — not board-mounted.**
   Accept the size/cost. Do **not** substitute a board-mount SHV PCB jack: every one found tops out at 3.5 kV continuous, i.e. no better than the part you rejected.

### KiCad footprint status
- **MKDS 10 HV/ 2-ZB-10,16** — footprint+symbol on **SnapMagic (SnapEDA)**, KiCad export available. Ready to use.
- **MKDS 5/2-9,5 and Weidmüller LU 10.16/2** — footprints on SnapMagic; also derivable from KiCad's `TerminalBlock_Phoenix` / `TerminalBlock` standard libraries.
- **Direct solder pad + Keystone turret (3A/3B)** — use KiCad `Connector_Pin` / `TestPoint` / `Mounting…` library footprints, or a trivial custom pad. Effectively no custom work.
- **SHV/MHV jacks (Cat 2)** — generally **custom footprint** needed (panel-mount; some on SnapMagic but verify before relying on it).

---

## Sources

- Radiall R317580000 (DigiKey): https://www.digikey.com/en/products/detail/radiall-usa-inc/R317580000/10521497
- Radiall SHV high-voltage connectors: https://www.radiall.com/products/rf-coaxial-connectors/high-voltage-connectors/shv.html
- JAW-DROPPER SVJ-05L SHV PCB-mount jack: https://antenna-connector.com/products/shv-jack-female-right-angle-connector-receptacle-pcb-mount/
- Amphenol RF MHV (000-27000, DigiKey): https://www.digikey.com/en/products/detail/amphenol-rf/000-27000/2643385
- Amphenol RF MHV connectors (5 kV class): https://www.amphenolrf.com/en-us/products/rf-connectors/mhv-connectors/
- Phoenix Contact MKDS 10 HV/ 2-ZB-10,16 (1709681): https://www.phoenixcontact.com/en-us/products/printed-circuit-board-terminal-mkds-10-hv-2-zb-1016-1709681
- Phoenix Contact MKDSP 10N/ 2-10,16 (1000 V, 10.16 mm): https://www.phoenixcontact.com/en-us/products/printed-circuit-board-terminal-mkdsp-10n-2-1016-1773976
- Phoenix Contact MKDS 10 HV footprint (SnapMagic/SnapEDA, KiCad): https://www.snapeda.com/parts/MKDS%2010%20HV/%202-ZB-10%2016/Phoenix%20Contact/view-part/
- Weidmüller terminal-block footprints (SnapEDA): https://www.snapeda.com/parts/1010300000/Weidmuller/view-part/
- Stäubli SLB4 4 mm panel socket (CAT ~1 kV, ruled out): https://www.staubli.com/us/en/electrical-connectors/products/t-m-products/products-for-test-accessories/sockets-2-mm-and-4-mm/panel-mount-socket-slb4-e.html
- HV silicone test-lead wire (DigiKey partgroup): https://www.digikey.com/catalog/en/partgroup/silicone-wire-test-leads/29052
- Genvolt HV silicone cable 10 kV-50 kV: https://www.genvolt.com/product/silicone-cable/
- Keystone turret terminals (DigiKey partgroup): https://www.digikey.com/catalog/en/partgroup/turret-terminals-keystone-electronics/23324
- IEC 60664-1 clearance/creepage calculator: https://tracewidthcalculator.com/clearance-creepage-calculator
- TI "Demystifying Clearance and Creepage for High-Voltage" (SLUP419): https://www.ti.com/lit/pdf/slup419
- Conformal coating effect on creepage (PD2->PD1): https://www.conformalcoating.co.uk/knowledge-hub/technical-articles/conformal-coating-design-hub/conformal-coating-clearance-creepage/
- Tyclon SHV ratings (rejected part, 3.5 kV continuous): https://tyclon.com/pages/shv-rf-coaxial-connectors

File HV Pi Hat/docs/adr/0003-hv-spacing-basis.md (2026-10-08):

# ADR-0003: HV spacing basis

- Status: Accepted 2026-10-08 (Anatol): option 2, encapsulate the HV zone. Fabrication stays
  blocked until the prerequisites under "Decision" are done and a qualified EE has signed off.
- Deciders: Anatol Gogoj (owner), reviewing EE (to be named)
- Supersedes: the "HV spacing" row of ADR-0001 (4 mm, then relaxed to 2 mm on 2026-06-08)
- Related: ADR-0002 (layer strategy), ADR-0004 (footprint)

## Context

`HV Pi Hat.kicad_dru` holds HV nets to 2 mm air clearance and 2 mm creepage (4 mm to the GND pour,
1 mm to drilled holes). The June build log justified 2 mm with "under IEC 60664 a coated surface
(pollution degree 1) drops the 5 kV creepage requirement to about 2 mm". No table was cited, and
the claim does not survive a lookup. Rev A passes DRC at 2 mm with zero HV violations, so DRC
cleanliness says nothing about whether 2 mm is adequate.

## What the standards say at 5 kV DC

| Source | Condition | Required | How it was read |
|---|---|---|---|
| IEC 60664-1:2020 Table F.5 | Creepage, pollution degree 1, any material (the printed-wiring columns stop at 1000 V) | **20 mm** (16 mm at 4000 V) | KiCad `pcb_calculator/calculator_panels/iec60664.cpp`, which cites "IEC60664-1 : 2020-05 Table F.5"; checked 2026-10-08. Secondary |
| IEC 60664-1:2020 Table F.5 | Creepage, pollution degree 2, material group IIIa/IIIb (FR4; Isola 370HR lists CTI 175 to 249 V) | **50 mm** | Same file. Secondary |
| IEC 60664-1:2020 Table F.8 | Clearance to withstand steady-state peaks, 5.0 kV, case A (inhomogeneous field, which PCB traces are) | **5.7 mm** (case B, homogeneous: 1.5 mm) | Same file. Secondary |
| IPC-2221B Table 6-1 | A5, conformal coating over the assembly: 0.8 mm + 0.00305 mm/V x (5000 - 500) V | **14.5 mm** | Altair Pollex transcription. Secondary. IPC-2221C (2023) changed the coated columns; values not found |
| IPC-2221B Table 6-1 | B1, internal conductors: 0.25 mm + 0.0025 mm/V x 4500 V | 11.5 mm | Same |
| IEC 60664-3 | Type 1 protection (coating) | Reduces the covered surface to pollution degree 1, so the 20 mm row applies. Requires a qualified coating covering 100 % of the gap | IEC webstore abstract. Primary |
| IEC 60664-3 | Type 2 protection (coating or potting acting as solid insulation) | Treated as solid insulation; minimum spacings are in its Table 1. **Table 1 values not found.** Qualified by test | IEC webstore abstract. Primary |
| IEC 61010-1 | Lab equipment, coatings to reach pollution degree 1 | Must meet Annex H. Insulation sizing applies where it protects against a hazard | Test report form text. Secondary |

Through the board, no standard found gives a long-term DC kV/mm limit for FR4. Isola 370HR lists
54 kV/mm short-term electric strength (IPC-TM-650 2.5.6.2A), and that method notes values "decrease
with increasing specimen thickness". Rev A has 1.96 mm of FR4 at its HV crossings, about 2.55 kV/mm
at 5 kV (ADR-0002).

IEC 60664-1's scope is equipment rated up to AC 1000 V or DC 1500 V, but it states that "higher
voltages can exist in internal circuits", and its tables extend past 5 kV.

## What it means for rev A

Re-running DRC on rev A with a coat-only basis (6 mm clearance, 20 mm creepage on HV nets) gives
**354 HV violations** (200 creepage, 154 clearance). A coat-only basis cannot be met on this board
or on the standard HAT+ outline of ADR-0004. The 2-channel active-discharge circuit needs on the
order of 20 mm between HV nodes, more than a third of the board's 56 mm height.

## Options

1. **Coat only (type 1).** 20 mm creepage, 6 mm clearance, qualified coating. Requires a board several
   times larger, or dropping channels or active discharge. Incompatible with ADR-0004.
2. **Encapsulate the HV zone (type 2 protection / solid insulation).** Pot the HV area (module
   outputs, optos' HV side, HV resistors, terminations) so the insulation is the potting compound,
   not air and a surface. Spacing then comes from IEC 60664-3 Table 1 and a qualification test (DC
   withstand above 5 kV plus partial discharge) instead of the creepage table. Needs a potting dam,
   a compound choice, and an outgassing check if the board will ever go to vacuum. ADR-0001 already
   lists "pot or encapsulate if more margin is needed".
3. **Documented functional-insulation deviation.** Keep coating and about 2 mm, classify HV-to-GND as
   functional insulation inside a closed enclosure, and justify by test. Whether the HV can be
   classed as functional depends on whether it is accessible: the DEA and its leads are outside the
   board, so this needs its own analysis under IEC 61010-1 clause 6. Weakest of the three.

## Decision

Option 2: encapsulate the HV zone (IEC 60664-3 type 2 protection, insulation treated as solid
insulation) and qualify it by test. It is the only sourced route that keeps the board near the
standard HAT+ outline (ADR-0004) without resting on an unsourced spacing figure.

Prerequisites before fabrication:

1. Get IEC 60664-3 Table 1 (type 2 minimum spacings) from the standard itself and set the DRC rules
   for the potted zone to it.
2. Pick a potting compound with a published dielectric strength and, given the extreme-environment
   work, a published outgassing figure.
3. Define the qualification test: DC withstand voltage, duration, and partial-discharge threshold,
   on a potted coupon or a first article.
4. Name the reviewing EE.

## Potting compound (prerequisite 2)

**Decided 2026-10-08 (Anatol): Sylgard 184, primed. Scope cut: this board is a lab instrument, not
flight hardware, so outgassing is not a selection criterion.** If the board ever has to sit inside a
vacuum or thermal-vacuum chamber, revisit with the space-grade shortlist below.

Sylgard 184 (Dow Corning form 06-1009-01): dielectric strength "540" V/mil (21.2 kV/mm), dielectric
constant 2.7 at 100 Hz, volume resistivity 1.2 x 10^14 ohm-cm, mixed viscosity 3,900 cP (flows under
U1 more easily than 93-500), service range "-45 to 200°C". "In applications requiring adhesion,
priming is required." Its datasheet lists cure inhibitors (organotin and other organometallic
compounds, among others), so boards must be clean before pouring. It is the same silicone the lab
already uses for DEA films. Electrically it is as good as 93-500; it fails only the NASA outgassing
screen as supplied (below), which no longer applies.

Space-grade shortlist considered first (2026-10-08), set aside on cost: DOWSIL 93-500 Space Grade
(about $1,300 per 110 g kit), fallback NuSil CV-2500.

| | DOWSIL 93-500 | NuSil CV-2500 | Stycast 2850FT + CAT 23LV |
|---|---|---|---|
| Chemistry | addition-cure silicone elastomer | addition-cure silicone elastomer | filled epoxy |
| Dielectric strength | "475 volts/mil" (19 kV/mm) | not in the TDS | 14.8 kV/mm |
| Dk | 2.6 at 100 Hz | not in the TDS | 5.36 at 1 MHz |
| Mixed viscosity | 8,100 cP | Part A 8,000 cP | 5,600 cP |
| Cure | 24 h at 25 C or 10 min at 100 C | 15 min at 150 C | 16 to 24 h at 25 C |
| Low temperature | TDS "-45 to 200°C" long term (2001 sheet: -115 C) | DMA Tg -130 C | Tg 40 to 55 C |
| ASTM E595 TML/CVCM | TDS 0.14/0.01; NASA DB 2018 lots 0.08/0.01 and 0.08/0.02 | TDS 0.05/0.01; NASA DB 0.06/0.01 | NASA DB 0.53/0.01, 0.49/0.01 |
| Primer | "priming will be required for many" (DC 1200 or P5200) | CF1-135 | none named |
| Availability | Ellsworth, in stock, 110 g kit about $1,300 | 50 to 500 g kits, no stock found | DigiKey/Mouser |

Sources: Dow TDS 11-1811-01 A and Form 10-951-01, NuSil CV-2500 Rev. B, Henkel Stycast 2850FT TDS,
NASA GSFC outgassing database (etd.gsfc.nasa.gov/capabilities/outgassing-database). Ruled out as
supplied by the NASA screen (CVCM 0.10 % or less): Sylgard 184 (0.92/0.40, 1.61/0.78) and RTV655
(3.55/0.96); only devolatilized lots pass.

Why 93-500: full electrical data, recent NASA entries, and stock. The bulk field is not the limit
(5 kV over 3 mm is 1.7 kV/mm, about 11 times below 19 kV/mm); the interfaces are. Its low Dk helps:
in a thin void across the field the void field is about the compound's Dk times the bulk field, 2.6x
for 93-500 against 5.4x for the epoxy. The epoxy's Tg sits inside the operating range and it is rigid.
About 15 g per board (both faces), so one 110 g kit covers a few boards plus test coupons. The cost
is the main drawback; Anatol decides the purchase.

## Interim layout rules (until prerequisite 1 is done)

These are working assumptions for placement and routing, not a qualified basis:

- Every piece of HV copper (pads, tracks, vias, and the THT solder joints on the far face) sits
  inside the potted zone. The THT HV parts put solder joints on B.Cu, so the zone is potted on
  both faces.
- Inside the zone: 2 mm minimum from HV copper to any other copper, the value rev A already meets.
  Placement studies also report how the layout behaves at 3 mm.
- The pot edge sits at least 3 mm outside any HV copper on both faces. HV leaves the zone only as
  insulated wire (the DEA leads), never as copper on the board surface. This rules out the J3/J4
  screw terminals: a terminal inside the pot cannot be used, and one outside it puts HV copper on
  an open surface. The outputs become soldered HV leads with strain relief, the first choice in
  `docs/HV_CONNECTOR_OPTIONS.md`.
- Copper that is not HV may sit inside the zone; the opto LED pins and the module's LV pins do.
- The bottom-face pot must stay clear of the Pi 5 below. HAT+ recommends 16 mm standoffs; the
  bottom pot height budget is not yet known.

`HV Pi Hat.kicad_dru` keeps the 2 mm rules until prerequisite 1 replaces them, and
`fab/README.md` keeps fabrication blocked.

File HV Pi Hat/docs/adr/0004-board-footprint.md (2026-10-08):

# ADR-0004: Board footprint: target the standard HAT+ outline

- Status: Accepted 2026-10-08. Rev B (issue #6) meets the outline; rev A (85 x 56 mm) did not. The
  placement study used 65 x 56.5 with the extra 0.5 mm on the wrong edge; rev B corrects it.
- Deciders: Anatol Gogoj
- Supersedes: the "Form factor 85 x 56 mm" row of ADR-0001
- Related: ADR-0002 (layer strategy), ADR-0003 (spacing basis)

## Position

Anatol is pushing to keep this board in the same footprint as a standard Raspberry Pi HAT:
65 x 56.5 mm with the standard mounting-hole pattern. The 85 x 56 mm outline used in rev A was a
concession to fit the HV zone at the spacing in force at the time. It is not the intended end
state, and further layout work should move toward the standard outline rather than away from it.

## Context

What the Raspberry Pi HAT+ specification says (build 2024-12-05,
https://datasheets.raspberrypi.com/hat/hat-plus-specification.pdf, and the legacy drawing
https://github.com/raspberrypi/hats/blob/master/hat-board-mechanical.pdf):

- Outline 65 x 56.5 mm (HAT+ figures 2 and 3); 3 mm corner radius (legacy drawing).
- Four M2.5 holes, "DRILLED TO 2.75mm +/- 0.05mm", on a 58 x 49 mm pattern, 3.5 mm from the edges.
  Holes ideally non-plated; if plated, isolated and not tied to GND.
- Standoffs: "provide at least 15mm board-to-board spacers; 16mm spacers are ideal".
- The hard requirements are the 40-way header including the ID pins, at least one hole aligned
  with a Pi hole, and the ID EEPROM of chapter 6. The spec is "less prescriptive about HAT
  physical dimensions", so an oversized board can still be a HAT+. The standard outline is
  therefore a design goal here (fit, stacking, cases, and no overhang over the Pi 5 USB and RJ45
  connectors), not a compliance requirement.

Rev A as built (measured from the board file 2026-10-08):

- Outline 85.05 x 56.05 mm, x 117.475 to 202.525, y 85.975 to 142.025 (board coordinates).
- Holes H1 to H4 at (121, 89.5), (179, 89.5), (121, 138.5), (179, 138.5): already the standard
  58 x 49 mm pattern, 3.5 mm from the left and top edges. A standard outline would end at
  x = 182.5 mm.
- Beyond x = 182.5 today: both output terminals J3 and J4, the right half of the SMHV0550 module
  (pins at x 170.95 to 187.46; body 0.85 x 0.85 in, about 21.6 mm square, per `docs/BOM_SOURCED.md`)
  and the right-hand pads of the four 17.6 mm HV resistors R1, R2, R25, R26 (pads at x 172.4 and
  187.6).
- The 20 mm extension overhangs the Pi 5 USB-A and RJ45 end, which is why rev A asks for 20 mm or
  taller standoffs instead of the 16 mm the spec recommends. The Pi 5 mechanical drawing does not
  publish connector heights, so that number is not verified.
- No ID EEPROM is fitted, and the GPIO map avoids ID_SD/ID_SC. To call the board a HAT+, an EEPROM
  must be added regardless of size.

## Decision

Target the standard HAT outline with the standard hole pattern and 3 mm corners. For this board's
through-hole GPIO header that is **65 x 56.0 mm**: the legacy HAT drawing reads "56.5mm FOR SMT STYLE
GPIO HEADER OTHERWISE 56.0mm FOR THROUGH HOLE HEADER", with the bottom holes 3.5 mm from the bottom
edge (the extra 0.5 mm of the SMT variant is on the header edge). Each mounting hole keeps a 6.2 mm
land free of other copper ("MIN. 6.2mm and EITHER ISOLATED COPPER OR BARE BOARD"). Rev A stays
85 x 56 mm as a prototype until a layout that meets the target and ADR-0003 exists.

## Consequences and the path to the standard outline

The HV zone has to lose about 20 mm of width: from x 163 to 202.5 today (39.5 mm) to x 163 to 182.5
(19.5 mm) if the LV and opto lanes stay where they are. The SMHV0550 body alone is 21.6 mm wide, so
the lanes have to compact too. Levers, in recommended order:

1. Replace the J3/J4 screw terminals with direct-soldered HV silicone leads and a strain relief.
   `docs/HV_CONNECTOR_OPTIONS.md` already ranks this first for a lab build, and it removes both
   terminals from the outline.
2. Compact the LV and opto lanes leftward to give the module a full-width slot inside x 182.5.
3. Look for physically shorter HV resistors for R_dis and R_safety than the 17.6 mm MHR0317
   bodies. No candidate part has been sourced yet.
4. Only if 1 to 3 fail: give up active discharge on one or both channels, which reverses an
   ADR-0001 decision.

Feasibility (2026-10-08): the placement study in `studies/hatplus/` (issue #4) routes the full
two-channel active-discharge circuit inside the 65 x 56.5 mm outline with the HV zone potted, using
levers 1 and 2 only, at both 2 mm and 3 mm HV spacing. It is a scripted feasibility layout, not a
finished one; its README lists what remains.

The spacing basis (ADR-0003) pulls the other way. Every millimeter added to the HV rule makes the
standard outline harder, so the placement study should run at the spacing ADR-0003 settles on,
not at today's provisional 2 mm.

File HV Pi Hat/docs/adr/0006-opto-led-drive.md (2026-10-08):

# ADR-0006: Opto LED drive current

- Status: Accepted 2026-10-08 (Anatol: "go for your recommendations"). Pending bench test T1
  (`docs/BENCH_TESTS.md`).
- Deciders: Anatol Gogoj
- Supersedes: the 51 Ohm opto-LED resistor value in ADR-0001 and `docs/CONTROL_DESIGN.md`

## Context

HVM OPTO-100-05 datasheet, Rev B (`datasheets/HVM_OPTO-100.pdf`):

- Table, p. 2: "DC Current Transfer Ratio 0.15%" (typical, no test condition given); "LED Forward
  Current 400 mA" and "LED Max Input Voltage 5 V" (absolute max); "LED Voltage Input @100mA Current
  Drive 3.25 V" (typical).
- Graph "Current Transfer Ratio (Iin vs Iout)", p. 3: output current is 0 at about 0.04 A of LED
  current and rises linearly to about 410 uA at about 0.31 A. The slope, 410 uA / 0.27 A, is the
  0.15 % of the table. So the 0.15 % is an incremental ratio above a threshold of roughly 40 mA.
- Graph "Vin vs Iout", p. 3: output current is 0 at about 2.25 V and about 410 uA at about 5.0 V.
  At the input voltage the old design produces (about 3.0 V) this graph gives roughly 100 uA, so the
  two graphs disagree.

The June design used 51 Ohm from +5 V: (5 - ~2.9 V) / (51 + ~3.5 Ohm) = about 38 mA, and assumed a
proportional CTR (0.15 % x 38 mA = 57 uA). By the CTR graph, 38 mA sits at the threshold and gives
close to no output current, so a channel might not charge at all.

In the active-discharge topology the only standing load on an output is the 1 GOhm bleeder (5 uA at
5 kV), so any output current well above 5 uA reaches full voltage; the current sets the speed.

## Decision

R6, R14, R21, R22 (opto LED resistors) become **15 Ohm, 1206**, Panasonic ERJ-P08J150V (listed at
2/3 W by distributors; confirm on the Panasonic datasheet when ordering).

- LED current: 5 - V_in = 15 I with V_in about 2.9 + 3.5 I (a fit through the datasheet's 3.25 V at
  100 mA) gives I = 2.1 / 18.5 = 114 mA, a little less with the MOSFET's on-resistance. Inside the
  400 mA absolute maximum.
- Output current: about (0.10 to 0.114 - 0.04) A x 0.15 % = 90 to 110 uA by the CTR graph, higher by
  the Vin graph.
- Resistor dissipation: 0.114^2 x 15 = 0.19 W, about 30 % of the 2/3 W listing.

## Consequences

- Full 0 to 5 kV swing on a 1 nF DEA: 1 nF x 5 kV / 100 uA = about 50 ms per edge, either direction.
  The SMHV0550's 200 uA is the ceiling for any further speed-up (shared by both channels).
- +5 V load from the drivers: at most one opto per channel is on, so up to about 230 mA, on top of
  the HV module and the indicator LEDs.
- The footprint grows from 0603 to 1206; rev B places it in the same spot next to each opto.
- Bench test T1 measures output current against LED current on one OPTO-100. If the threshold is
  not real, 15 Ohm is still fine (faster, same limits); if the measured current at about 110 mA is
  below about 50 uA, revisit.

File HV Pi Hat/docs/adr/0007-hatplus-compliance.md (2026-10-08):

# ADR-0007: HAT+ compliance: ID EEPROM, underside GPIO socket, unplated mounting holes

- Status: Accepted 2026-10-08 (Anatol: "go for your recommendations")
- Deciders: Anatol Gogoj
- Related: ADR-0004 (outline), ADR-0005 (stack height)

## Context

Raspberry Pi HAT+ specification (RP-008281-DS-1) and the legacy HAT mechanical drawing
(github.com/raspberrypi/hats, hat-board-mechanical.pdf) require or recommend:

- Ch. 3: an ID EEPROM read at boot; "Use a 24Cxx 3.3V I2C EEPROM", "16-bit addressable", "with a
  write protect (WP) pin that protects the entire device memory", no clock stretching, no paged
  addressing. Recommended part: "OnSemi CAT24C32". Write protect: "connect the EEPROM write protect
  pin to a test point on the board pulled-up to 3.3V with a 1KΩ resistor".
- Ch. 2 (important note): "The only permitted connections to the ID_SC and ID_SD (GPIO0 and GPIO1)
  pins are an ID EEPROM and the required 3.9KΩ pull-up resistors to 3.3V."
- Ch. 3.1: address 101_00XY; XY = 00 is the Standard class (a HAT+ that uses GPIOs 2 to 27).
- Ch. 2.2: a HAT+ "must be electrically compatible with the STANDBY state" (only 5 V powered).
- Drawing: mounting holes "should ideally be non-plated", drilled 2.75 +/- 0.05 mm, land at least
  6.2 mm of isolated copper or bare board.

## Decision

1. **ID EEPROM** U3 = OnSemi CAT24C32 (SOIC-8; the KiCad 24LC16 symbol supplies the 24Cxx pinout).
   A0 to A2 to GND (address 0x50, Standard class). R27/R28 3.9 kOhm pull-ups on ID_SD/ID_SC to
   +3V3 (header pin 1), R29 1 kOhm WP pull-up with test point TP1, C6 100 nF decoupling.
2. **GPIO socket on the underside**: GPIO1 uses the bottom-side PinSocket_2x20 footprint (same pad
   positions as before, checked pad by pad); the part is the elevated socket of ADR-0005.
3. **Mounting holes** H1 to H4: unplated 2.75 mm (`HV_Footprints:MountingHole_2.75mm_M2.5_NPTH_HAT`)
   with a 6.2 mm copper-free land kept by rule areas. This also removes the last floating copper
   rings near the potted zone.

## Consequences

- STANDBY: with only 5 V up, the GPIO pins and 3.3 V are unpowered. The MOSFET gates have 10 kOhm
  pull-downs and PGM is held at 0 V by R8 (100 kOhm), so the HV module is programmed to 0 V and no
  opto conducts. Bench test T7 checks this.
- The EEPROM must be programmed (product UUID, vendor and product strings, and a Device Tree overlay
  name are required or recommended by ch. 3) before the board can be called a HAT+. The overlay that
  configures GPIO5/6/16/26 and the GPIO12 PWM is a firmware task, not yet written.
- Schematic parity: H1 to H4 remain board-only footprints (no schematic symbols), as in rev A.

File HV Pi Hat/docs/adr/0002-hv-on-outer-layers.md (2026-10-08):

# ADR-0002: HV on the outer layers, inner layers voided, thick stackup

- Status: Accepted 2026-06-08 (the build log calls it "Decision A1"); stackup revised 2026-10-08
- Deciders: Anatol Gogoj
- Related: ADR-0003 (spacing basis), ADR-0004 (footprint)

## Context

Routing the 2-channel active-discharge HV zone needed about 2 mm spacing (ADR-0003). The first
idea was to bury HV on In1/In2 inside the FR4. Review found a 3-D hazard the 2-D DRC cannot see:
on a standard 1.6 mm 4-layer stack, the outer-to-inner prepreg is about 0.1 to 0.21 mm, so HV on
any layer faces adjacent-layer copper at up to about 24 kV/mm (5 kV / 0.21 mm).

## Decision

1. All five HV nets (`/HV_RAIL`, `/HV_CH1`, `/HV_CH2`, `/HV_CH1_DIS`, `/HV_CH2_DIS`) are routed on
   F.Cu and B.Cu only, 0.25 mm wide. Where two HV nets must cross, they use opposite outer layers.
2. In1.Cu and In2.Cu carry rule-area keepouts (no tracks, vias or fills) over the HV zone,
   board coordinates x 163.0 to 202.5 mm, y 94.5 to 142.0 mm.
3. Placement uses lanes: LV drivers on the left, the opto column in the middle (LED pins facing
   left, HV pins facing right), all HV parts on the right. LV signals do not cross the HV zone;
   the only LV copper inside it is the corridor along the SMHV0550 LV pin column (U1 pins 1 to 7).
4. The floating 5.4 mm copper pads on mounting holes H1 to H4 were removed (a floating plate near
   5 kV charges to an intermediate potential). The 3.1 mm plated ring remains.
5. Stackup: JLCPCB JLC04201H-7628D, 4 layers, 2.0 mm nominal. Layer by layer (mm): F.Cu 0.035,
   7628 x4 prepreg 0.864, In1 0.0152, core 0.2, In2 0.0152, 7628 x4 prepreg 0.864, B.Cu 0.035.
   Source: jlcpcb.com/impedance, 2.0 mm tab, read 2026-10-08. This is encoded in the board file.

The June version of this decision asked for a 2.0 to 2.4 mm custom stackup. JLCPCB does not offer
that for 4 layers: the capabilities page lists FR4 thicknesses up to 2.0 mm ("2.5 mm and above are
for 12+ layer PCBs only"), and the order form offers only six fixed 2.0 mm stackups for 4 layers
with no custom option. 7628D is the preset with the thickest outer prepreg, which is the dimension
this decision depends on.

## Consequences

- Measured on the board (2026-10-08, conservative shapes): the smallest 3-D gap between HV copper
  and non-HV copper on a different layer is 1.91 mm (HV_RAIL on B.Cu to the U1.9 GND annular ring on
  In2). An HV_RAIL track on B.Cu passes directly under a GND track on F.Cu with 1.96 mm of FR4
  between them. At 5 kV that is an average field of 2.5 to 2.6 kV/mm, before edge enhancement.
- Where CH1 and CH2 cross on opposite faces, the two can differ by the full 5 kV (one charged, one
  discharged): 5 kV across 1.96 mm of FR4, about 2.55 kV/mm. The June log set a long-term target of
  2 kV/mm or less but gave no source for it. Whether 2.5 kV/mm through FR4 is acceptable is part of
  ADR-0003.
- The 2-D DRC enforces the in-plane rules only. The through-board numbers above have to be
  re-measured after any HV re-route (the script used is described in `docs/TOOLING.md`).
- The order must name the stackup explicitly (JLC04201H-7628D). A default 2.0 mm order gets
  JLC04201H-7628, whose outer prepreg is 0.21 mm.

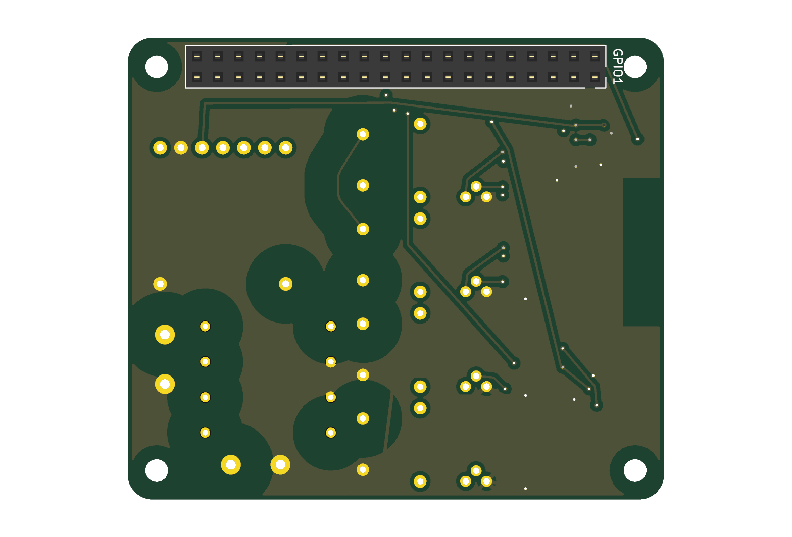
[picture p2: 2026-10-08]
HV Pi Hat/docs/revB_bottom.png

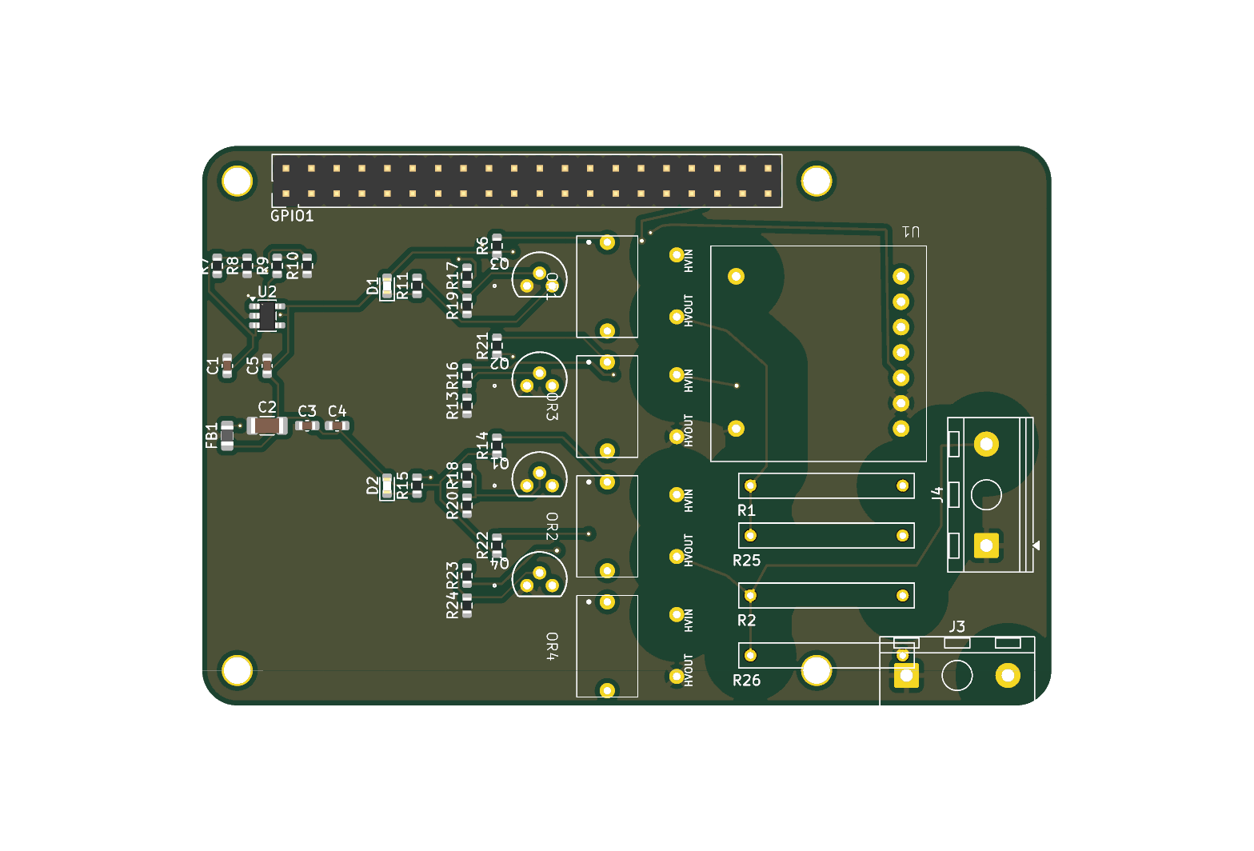
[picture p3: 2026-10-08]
HV Pi Hat/docs/A1_final_top.png

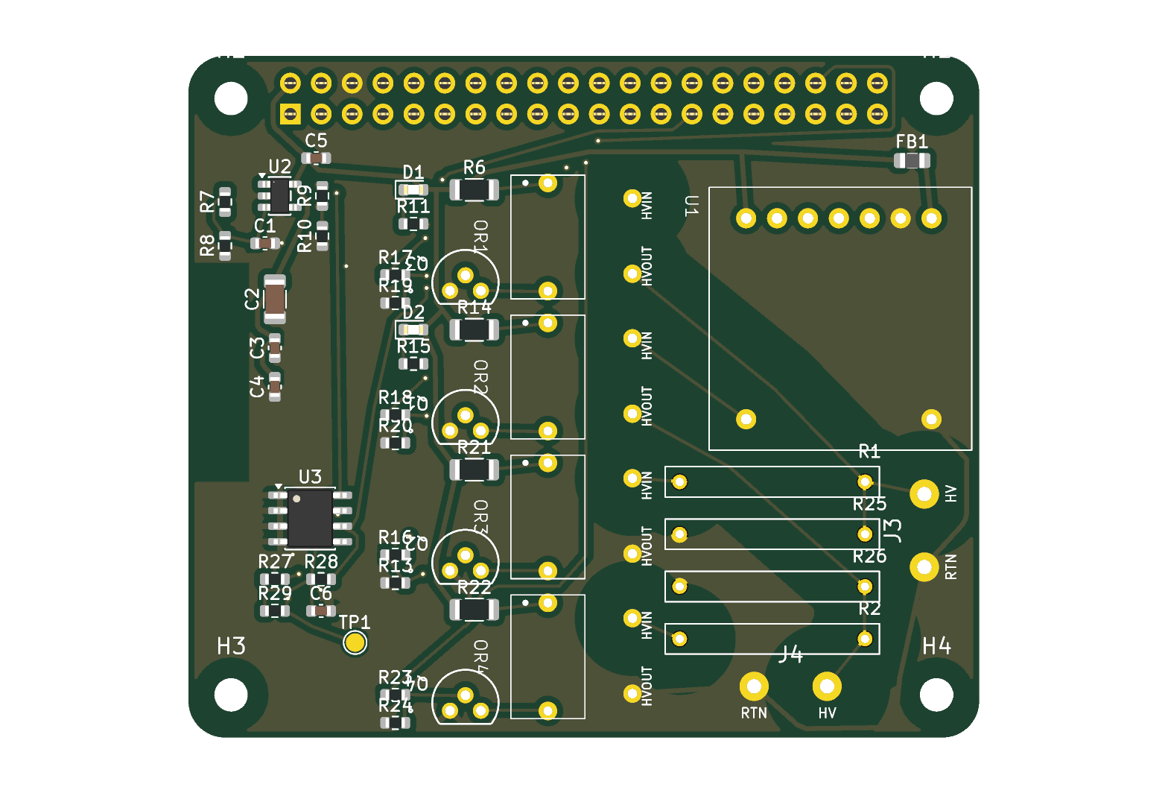
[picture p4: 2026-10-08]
HV Pi Hat/docs/revB_top.png

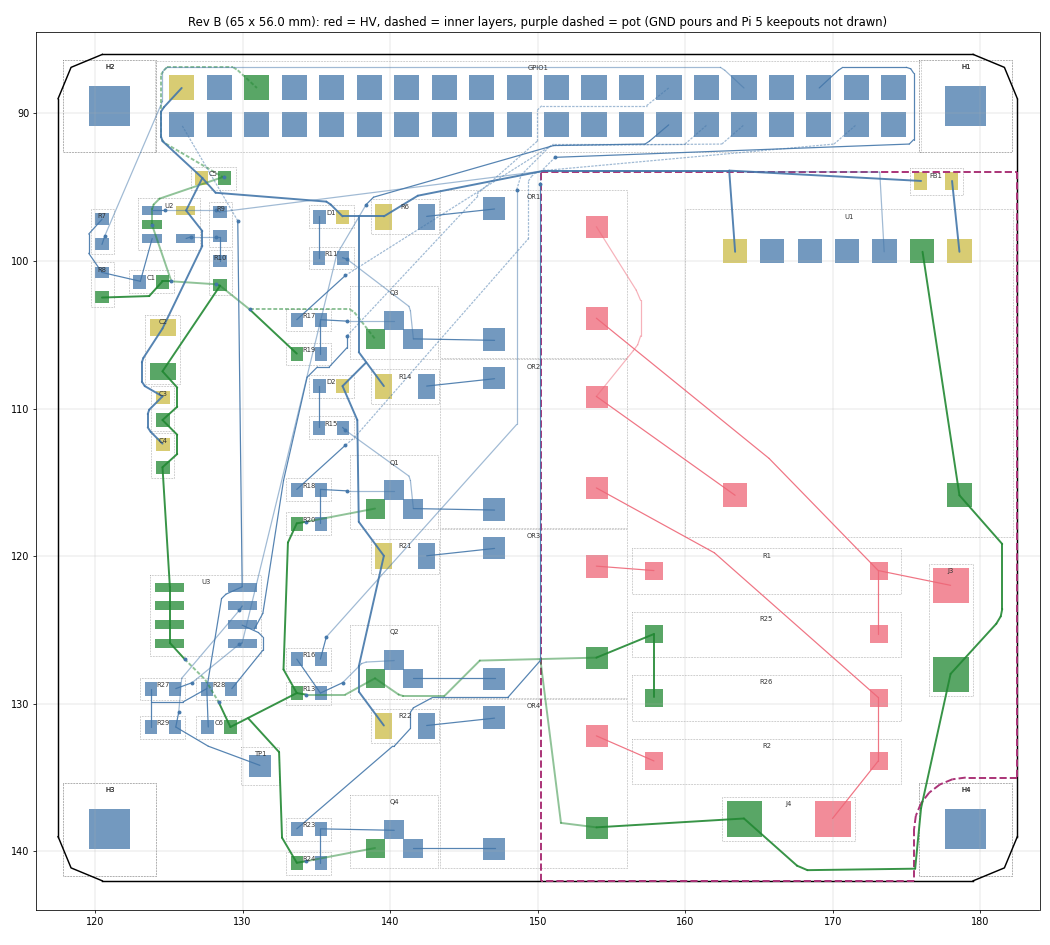
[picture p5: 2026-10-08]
HV Pi Hat/docs/revB_routed.png

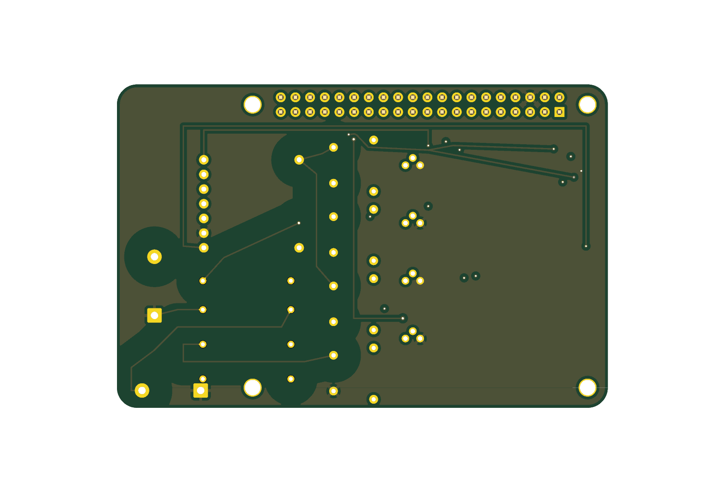
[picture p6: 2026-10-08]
HV Pi Hat/docs/A1_final_bottom.png

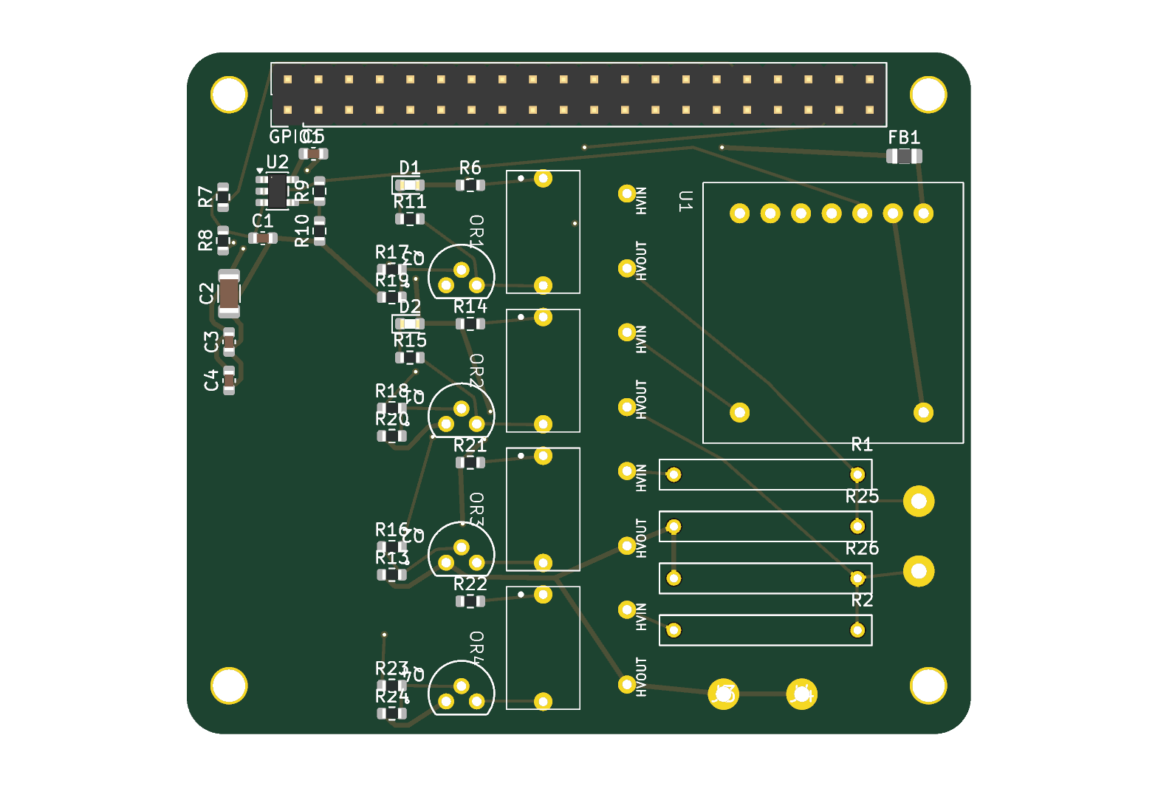
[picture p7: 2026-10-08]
HV Pi Hat/studies/hatplus/hatplus_top3d.png

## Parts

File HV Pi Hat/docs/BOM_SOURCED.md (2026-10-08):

# Sourced Bill of Materials — 5 kV HV Raspberry Pi HAT (DEA driver)

**Date sourced:** 2026-06-07
**Distributors:** DigiKey preferred, Mouser/LCSC as fallback.
**Verification:** Specialty/high-risk parts (HVM modules, SHV connector, 1 GΩ HV resistor, TN0610 MOSFET) verified via live web lookups. Commodity passives use representative in-stock DigiKey catalog parts per value.

> **Pricing note:** DigiKey's product pages block automated reads (HTTP 403), so unit prices marked "~" were obtained from search snippets / mirror distributors and should be confirmed at checkout. Stock figures are approximate as of the date above.

---

## BOM Table

| Ref(s) | Qty | Value/Part | Package | Manufacturer + MPN | DigiKey/Mouser PN | In stock? (Y/N + approx qty) | Unit price | Notes |
|---|---|---|---|---|---|---|---|---|
| U1 | 1 | SMHV0550 — 5 kV / 200 µA programmable HV DC-DC | Module 0.85"x0.85"x0.6" | HVM Technology SMHV0550 | DigiKey **2244-SMHV0550-ND** (base), product 10708015 | Y — stocked catalog item ("ships today"); typically low/MOQ-of-1 qty, confirm at cart | ~$200–300 (confirm) | **Catalog item on DigiKey — no RFQ needed.** Output proportional to 0–5 V program input. 5 V ±10% supply. Also orderable direct from hvmtech.com (RFQ, tel 830-626-5552). The "-S2" suffix is a packaging/variant; the bare **SMHV0550** matches the schematic symbol. |
| OR1–OR4 | 4 | OPTO-100-05 — 10 kV HV opto-coupler | Epoxy body 0.40"L x 0.24"W x 0.25"H (10.2 x 6.1 x 6.4 mm), LED pins 0.350" apart, HV on flying wire leads (datasheet Rev B, p. 2) | HVM Technology OPTO-100-05 | DigiKey **2244-OPTO-100-05-ND**, product 16378579 | Y — stocked catalog item ("ships today") | ~$94.74 DK (≈$74 at LCSC C17566441) | **Catalog item on DigiKey — orderable, not RFQ-only.** 10 kV reverse-voltage rating, internal current-limit R, no external parts. LED Vf = 3.25 V @ 100 mA. **4 needed = ~$380 — largest BOM cost driver after U1.** |
| U2 | 1 | MCP6001 op-amp, 1 MHz RRIO | SOT-23-5 ("OT") | Microchip MCP6001T-I/OT | DigiKey **MCP6001T-I/OTCT-ND** (cut tape), product 551760 | Y — high stock (mainstream part) | ~$0.42 | "OT" = SOT-23-5 per schematic (symbol MCP6001-OT). I-grade (-40…+85 °C). |
| Q1–Q4 | 4 | N-MOSFET, 100 V, logic-level | TO-92 | Microchip (Supertex) TN0610N3-G | DigiKey **TN0610N3-G-ND**, product 4902374 | Y — **active, ships today** | ~$0.70 | 100 V Vds, 500 mA, Vgs(th) typ ~1.5 V (logic-level), 1 W. Confirmed NOT EOL. Schematic uses the **-P013** ammo/tape variant (DigiKey **TN0610N3-G-P013** / Mouser 579-TN0610N3-G-P013) — order whichever pack form you prefer; die is identical. See alternatives note below. |
| R1, R2 | 2 | 100 MΩ HV resistor, 1%, 7 kV | Axial 0317 (lead pitch 15.24 mm) | Murata MHR0317SA107F70 | DigiKey **MHR0317SA107F70-ND** (verify current DK#); confirmed catalog part | Y — ~4,155 (mirror); on DigiKey catalog | ~$1.10 (qty1), ~$0.37 @1k | 100 MΩ confirmed (107 = 100 MΩ). 0.8 W. Matches schematic symbol/footprint exactly. |
| R25, R26 | 2 | 1 GΩ HV resistor, 1%, 7 kV (populated by default as the fail-safe bleeder; DNP-able) | Axial 0317 (lead pitch 15.24 mm) | Murata MHR0317SA108F70 | DigiKey product **9950895** (DK# MHR0317SA108F70-ND) | **Partial** — real Murata catalog part with live DigiKey page; one mirror showed 0 stock, so **verify live stock before ordering** | ~$1.10 (qty1) | **CONFIRMED this 1 GΩ part exists** in the same 0317 series (108 = 1000 MΩ). 7 kV rated, 0.8 W. Populated by default (fail-safe bleed-down), so stock matters: verify before ordering. Fallback if DK out: Ohmite "Slim-Mox"/Vishay VR37 GΩ-range HV axials (≥5 kV), or Vishay VHV/RNX. |
| J3, J4 | 2 | Soldered HV lead pair per channel (pad 1 return/GND, pad 2 HV), potted in place (ADR-0003) | THT, footprint `HV_Footprints:HV_LeadPair_P6.00mm` (2.4 mm pads, 1.2 mm drill, 6.0 mm pitch) | Wire: HV silicone, 10 kV or higher rated, 18 to 20 AWG (part not yet chosen) | See `docs/HV_CONNECTOR_OPTIONS.md` | n/a | n/a | Rev B replaced the 10.16 mm screw terminals: a terminal cannot sit inside the pot. Ranked first in the connector study. |
| GPIO1 | 1 | 2x20 (40-pin) 2.54 mm female header. **Superseded by ADR-0005 (20 mm stack): proposed Samtec ESQ-120-14-G-D elevated socket, pending the Pi pin-height measurement** | THT, dual row | Sullins PPTC202LFBN-RC (8.51 mm body, about 11 mm stack: too short for 20 mm) | DigiKey **S6104-ND**, product 807240 | Y — high stock | ~$1.10 | Plain 2x20 female socket (non-stacking). For a stacking/extended HAT header use Samtec SSQ-120-03-T-D or Sullins PPPC202LFBN-RC (S7123-ND). |
| D1, D2 | 2 | LED indicator, ~2 V | 0603 | Würth 150060GS75000 (green) | DigiKey **732-4971-1-ND** | Y — very high stock | ~$0.12 | Any 0603 LED is fine; green Vf ~2.0 V. Pair with appropriate series R (see 470 Ω / 1 k). |
| FB1 | 1 | Ferrite bead, 600 Ω @ 100 MHz, ≥0.5 A | 0805 | Murata BLM21AG601SN1D | DigiKey **490-1054-1-ND**, product 584251 | Y — very high stock | ~$0.10 | 600 Ω @100 MHz, 600 mA. For higher current use BLM21SP601SH1D (2.3 A, power line). |
| C2 | 1 | 47 µF, ≥10 V, X5R/X7R MLCC | 1206 | Murata GRM31CR61A476KE15L (47 µF 10 V X5R) | DigiKey **490-5523-1-ND** | Y — high stock | ~$0.30 | 1206, 10 V X5R. For more margin use 16 V (GRM31CR61C476K). |
| C1, C3 | 2 | 1 µF, ≥16 V MLCC | 0603 | Murata GRM188R61E105KA12D (1 µF 25 V X5R) | DigiKey **490-5523-2-... / 490-1543-1-ND** | Y — very high stock | ~$0.10 | 0603, 25 V X5R (>16 V margin). |
| C4, C5 | 2 | 0.1 µF, ≥16 V MLCC | 0603 | Murata GRM188R71H104KA93D (0.1 µF 50 V X7R) | DigiKey **490-3553-1-ND** | Y — very high stock | ~$0.10 | 0603, 50 V X7R. |
| R6, R14, R21, R22 | 4 | 15 Ω opto-LED resistors (ADR-0006), about 0.19 W each at ~110 mA | 1206 | Panasonic ERJ-P08J150V (listed 2/3 W; confirm on the Panasonic datasheet) | Not re-checked | Not re-checked | n/a | Replaces the 51 Ω 0603 (Yageo RC0603FR-0751RL). |
| R11, R15 | 2 | 470 Ω, 1% | 0603 | Yageo RC0603FR-07470RL | DigiKey **311-470HRCT-ND** | Y — very high stock | ~$0.10 | LED series resistors (with D1/D2). |
| R16, R17, R18, R23 | 4 | 100 Ω, 1% | 0603 | Yageo RC0603FR-07100RL | DigiKey **311-100HRCT-ND** | Y — very high stock | ~$0.10 | |
| R7, R10, R13, R19, R20, R24 | 6 | 10 kΩ, 1% | 0603 | Yageo RC0603FR-0710KL | DigiKey **311-10.0KHRCT-ND** | Y — very high stock | ~$0.10 | |
| U3 | 1 | HAT+ ID EEPROM, 32 Kb, 3.3 V I2C, WP protects whole array | SOIC-8 | OnSemi CAT24C32 (HAT+ spec 3.3.1 recommended part) | Not re-checked | Not re-checked | n/a | ADR-0007. Avoid Microchip variants whose WP does not cover the whole array (spec warning). |
| R27, R28 | 2 | 3.9 kΩ ID_SD/ID_SC pull-ups to 3.3 V (HAT+ spec ch. 2) | 0603 | Any 1 % thick film | Not re-checked | Not re-checked | n/a | |
| R29 | 1 | 1 kΩ WP pull-up (HAT+ spec 3.3) | 0603 | Any 1 % thick film | Not re-checked | Not re-checked | n/a | TP1 (bare pad, not in BOM) on WP for programming. |
| C6 | 1 | 0.1 µF EEPROM decoupling | 0603 | Same as C4/C5 | | | | |
| H1-H4 | 4 | Mounting holes, unplated 2.75 mm, 6.2 mm copper-free land | NPTH | n/a | | | | ADR-0007; 20 mm M2.5 standoffs (ADR-0005). |
| R8 | 1 | 100 kΩ, 1% | 0603 | Yageo RC0603FR-07100KL | DigiKey **311-100KHRCT-ND** | Y — very high stock | ~$0.10 | |
| R9 | 1 | 5.6 kΩ, 1% | 0603 | Yageo RC0603FR-075K6L | DigiKey **311-5.60KHRCT-ND** | Y — very high stock | ~$0.10 | |

---

## SOURCING RISKS (needs user attention)

1. **SHV connector (J3, J4) — RESOLVED 2026-06-07 → now a 1×2 screw terminal.**
   > **UPDATE:** J3/J4 are no longer SHV. Per the user decision they are now a generic **1×2 screw
   > terminal, 10.16 mm pitch** (`TerminalBlock_RND_205-00241`, pitch-compatible with **Phoenix MKDS
   > 10 HV / 1709681**); see the dedicated study `docs/HV_CONNECTOR_OPTIONS.md`. **Correction to the
   > note below:** the Radiall **R317580000 operating rating is ~3.5 kV** (its 12 kV is only mated-pair
   > *withstand*), so it does **not** solve the continuous-rating problem either; no board-mount SHV
   > jack exceeds 3.5 kV continuous. The genuinely-safe 5 kV options are panel-mount MHV/Radiall
   > (operating-rated) or a **direct-soldered HV silicone lead** (best). Original SHV note kept below.

1b. **(superseded) Original SHV note.**
   - The schematic footprint is named `4912-SHV-R-ND`, which mixes two unrelated parts: **Keystone 4912** is a 0.25" quick-fit *terminal* (not SHV), while **SHV-R** is the **Tyclon** SHV jack. The actual orderable SHV jack is **Tyclon SHV-R** (DigiKey marketplace 19092455, ~$12.08, ~929 in stock).
   - **Problem:** the Tyclon SHV line is rated **3.5 kV continuous, 5 kV withstand for 1 minute only.** Running it at 5 kV *continuous* gives essentially zero margin and is outside its continuous rating.
   - **Recommended fix:** use **Radiall R317580000** (DigiKey, ~$29.60; mated pair rated **12 kVDC**) for real ≥5 kV margin. Caveat: it is a panel-mount **bulkhead/solder-cup** SHV receptacle, not a board-mount PCB jack — you'd mount it to the enclosure and wire to the PCB (good HV practice anyway). Distributor listings disagree on male/female and "plug vs receptacle," so **confirm gender/mate against your cable before ordering.** Verify final DigiKey PN at checkout.
   - Action: decide enclosure-mount (Radiall, recommended for 5 kV) vs. board-mount (Tyclon, only acceptable if actual operating voltage stays well under 3.5 kV).

2. **U1 SMHV0550 (5 kV DC-DC module) — specialty, but stocked.**
   - Good news: it IS a DigiKey catalog item (product 10708015, "ships today"), so **no RFQ is strictly required.** Also available direct from hvmtech.com. Expect ~$200–300/unit; confirm exact price + live stock at cart (DigiKey blocks automated price scraping). If DigiKey shows 0, lead time direct from HVM can be multiple weeks.

3. **OR1–OR4 OPTO-100-05 (10 kV opto) — specialty, stocked, and the dominant passive cost.**
   - Catalog item on DigiKey (product 16378579), ~$94.74 each → **~$380 for the 4 needed.** Cheaper at LCSC (~$74, C17566441) if you can use that channel. Confirm live stock; if short, HVM direct or Luso Electronics (UK) carry it.

4. **R25/R26 1 GΩ HV resistor (MHR0317SA108F70) — confirmed real, but verify live stock.**
   - The 1 GΩ / 7 kV / 0317 part exists with a live DigiKey page (product 9950895). One mirror distributor showed 0 stock, so **check DigiKey stock before relying on it.** Because these are DNP/optional, this is low-impact. Fallback ≥5 kV 1 GΩ axials: Ohmite Slim-Mox, Vishay VR37, or Caddock MX/MG series.

5. **TN0610N3-G (Q1–Q4) — verified ACTIVE, low risk.**
   - Confirmed in stock and not EOL (DigiKey 4902374, "ships today"; also Mouser, RS, TME). Schematic specifies the **-P013** ammo-pack variant — same die, just packaging. If you ever need a second source, pin/spec-compatible TO-92 logic-level N-MOSFETs ≥100 V: **Diodes/Zetex ZVN4310A** (100 V, Vgs(th) ≤2.5 V) or **BSS127S-class** (note SOT-23, not TO-92). For exact TO-92 footprint, Microchip **TN0702N3-G** (200 V sibling) is the closest family alternative.

---

## Source links

- SMHV0550 (DigiKey): https://www.digikey.com/en/products/detail/hvm-technology-inc/SMHV0550/10708015
- SMHV series (HVM): https://www.hvmtech.com/smhv-series
- OPTO-100-05 (DigiKey): https://www.digikey.com/en/products/detail/hvm-technology-inc/OPTO-100-05/16378579
- OPTO-100-05 (HVM): https://www.hvmtech.com/opto100
- OPTO-100-05 (LCSC): https://www.lcsc.com/product-detail/C17566441.html
- MHR0317SA107F70 (Murata/DigiKey via mirror): https://www.xonelec.com/mpn/murata/mhr0317sa107f70
- MHR0317SA108F70 (DigiKey): https://www.digikey.com/en/products/detail/murata-power-solutions-inc/MHR0317SA108F70/9950895
- Tyclon SHV-R (DigiKey): https://www.digikey.com/en/products/detail/tyclon/SHV-R/19092455
- Tyclon SHV voltage ratings: https://tyclon.com/pages/shv-rf-coaxial-connectors
- Radiall R317580000 (DigiKey): https://www.digikey.com/en/products/detail/radiall-usa-inc/R317580000/10521497
- MCP6001T-I/OT (DigiKey): https://www.digikey.com/en/products/detail/microchip-technology/MCP6001T-I-OT/551760
- TN0610N3-G (DigiKey): https://www.digikey.com/en/products/detail/microchip-technology/TN0610N3-G/4902374
- Sullins PPTC202LFBN-RC (DigiKey): https://www.digikey.com/en/products/detail/sullins-connector-solutions/PPTC202LFBN-RC/807240
- BLM21AG601SN1D ferrite (DigiKey): https://www.digikey.com/en/products/detail/murata-electronics/BLM21AG601SN1D/584251

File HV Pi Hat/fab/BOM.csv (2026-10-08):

Reference | Value | Footprint | QUANTITY | DNP
C1,C3 | 1 uF | Capacitor_SMD:C_0603_1608Metric | 2
C2 | 47 uF | Capacitor_SMD:C_1206_3216Metric | 1
C4,C5,C6 | 0.1 uF | Capacitor_SMD:C_0603_1608Metric | 3
D1,D2 | LED | LED_SMD:LED_0603_1608Metric | 2
FB1 | FerriteBead | Inductor_SMD:L_0805_2012Metric | 1
GPIO1 | Samtec ESQ-120-14-G-D | Connector_PinSocket_2.54mm:PinSocket_2x20_P2.54mm_Vertical | 1
J3,J4 | HV_LeadPair | HV_Footprints:HV_LeadPair_P6.00mm | 2
OR1,OR2,OR3,OR4 |  | HV_Footprints:HVM OR-100 | 4
Q1,Q2,Q3,Q4 |  | TN0610N3_G_P013_Footprint:TO-92_MC_MCH | 4
R1,R2 | 100 M | MHR0317SA107F70:RESRR1524W50L1760T250H500 | 2
R6,R14,R21,R22 | 15 | Resistor_SMD:R_1206_3216Metric | 4
R7,R10,R13,R19,R20,R24 | 10k | Resistor_SMD:R_0603_1608Metric | 6
R8 | 100k | Resistor_SMD:R_0603_1608Metric | 1
R9 | 5.6k | Resistor_SMD:R_0603_1608Metric | 1
R11,R15 | 470 | Resistor_SMD:R_0603_1608Metric | 2
R16,R17,R18,R23 | 100 | Resistor_SMD:R_0603_1608Metric | 4
R25,R26 | 1G | MHR0317SA107F70:RESRR1524W50L1760T250H500 | 2
R27,R28 | 3.9k | Resistor_SMD:R_0603_1608Metric | 2
R29 | 1k | Resistor_SMD:R_0603_1608Metric | 1
U1 |  | HV_Footprints:SMHV0550 | 1
U2 | MCP6001-OT | Package_TO_SOT_SMD:SOT-23-5 | 1
U3 | CAT24C32 | Package_SO:SOIC-8_3.9x4.9mm_P1.27mm | 1

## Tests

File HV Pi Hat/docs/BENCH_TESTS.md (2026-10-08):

# Bench tests: HV Pi Hat rev B

Measurements the design depends on that no datasheet or drawing settles. Results go in GitHub issue
#7; anything that changes the design goes into an ADR. Work at or below the stated voltages
with a current-limited supply, and discharge HV nodes before touching them.

## Before ordering rev B

### T1. OPTO-100-05 output current vs LED current (ADR-0006)
- Why: the datasheet's CTR graph has a turn-on threshold near 40 mA, its Vin graph does not, and
  rev B's 15 Ohm LED resistors assume the threshold is real.
- Setup: one OPTO-100-05. LED pins 2 (+) and 1 (-) from a current-limited bench supply, 20, 40, 60,
  80, 100, 120, 150 mA (400 mA absolute max). HV leads reverse biased from a low-voltage supply
  (30 to 100 V is enough for photocurrent): RED (cathode) to +, WHITE (anode) to the return through
  a uA meter. Polarity read from the datasheet's application schematic.
- Record: output current at each LED current, and at 0 mA (dark current).
- Pass: at least 50 uA at 110 mA LED current. Record where the output starts to rise.

### T2. OPTO-100-05 HV lead polarity vs the footprint (assembly check)
- Why: a reversed photodiode is forward biased and conducts with no light. The charge opto would
  then hold the DEA at the rail; the discharge opto would short it.
- Check: in the T1 setup, the diode conducts only with RED positive and the LED on. On the board,
  RED goes to the pad at the higher potential: pad 3 of each opto (HV_RAIL for OR1/OR2,
  HV_CHx_DIS for OR3/OR4), WHITE to pad 4 (HV_CHx for OR1/OR2, GND for OR3/OR4). Confirm against
  the footprint's HVIN/HVOUT silkscreen before soldering any opto.

### T3. Raspberry Pi 5 GPIO pin height (ADR-0005)
- Why: the Samtec ESQ-120-14-G-D elevated socket needs at least 3.68 mm of pin engagement, and no
  official drawing gives the Pi 5 header heights.
- Measure with calipers on the bench Pi: h_b = top of the header's plastic base above the Pi PCB,
  h_p = pin tip above the Pi PCB.
- Pass: h_p - h_b >= 3.68 mm.

### T4. Active Cooler height (ADR-0005, informational)
- Measure the highest point of the fitted Active Cooler above the Pi PCB (fan frame and push-pin
  caps). The 20 mm stack assumes 13.70 mm or less.

## On the first article

### T5. Potting qualification (ADR-0003 prerequisite 3; compound Sylgard 184, primed)
- DC withstand voltage, duration and partial-discharge limits come from IEC 60664-3 once the
  standard is in hand. Run on potted coupons and the first article.
- Adhesion: coupons with the board's actual solder mask, primed and unprimed; peel test, look for
  cohesive failure (the Dow sheet's stated aim).
- Cure inhibition: the Sylgard 184 datasheet lists inhibitors (organotin and other organometallic
  compounds among them). Clean the board, then check the interface for uncured material.
- Voids under U1 (its HV pin is under the module body): pour under vacuum, section one sample.
- Thermal cycling over the lab operating range (the datasheet service range is -45 to 200 C); DC
  withstand and PD inception before and after (rising PD means delamination).
- Not in scope (lab instrument, ADR-0003): thermal vacuum, low-pressure PD, outgassing.

### T6. SoC temperature with the HAT fitted (ADR-0005)
- The Active Cooler's fan inlet sits about 3.3 mm under the bottom pot.
- 10 min CPU load (e.g. stress-ng) with and without the HAT; log `vcgencmd measure_temp` and
  `vcgencmd get_throttled`.
- Pass: no throttling flags with the HAT fitted.

### T7. STANDBY and boot fail-safe (ADR-0007)
- Put the Pi in STANDBY (EEPROM `POWER_OFF_ON_HALT=1`, then `sudo halt`) with the HAT powered, and
  watch a full boot from cold.
- Pass: the HV rail and both outputs stay at about 0 V throughout (no opto conducts, PGM stays low).

### T8. Bleed-down when unpowered (1 GOhm safety bleeders R25/R26)
- Charge an output with a 1 nF load to about 1 kV, remove all power, record the decay.
- Expected time constant: 1 GOhm x 1 nF = 1 s. An HV probe's own input resistance (often about
  1 GOhm) is in parallel and shortens it; account for it.
- Pass: below 50 V within 10 s.

### T9. Functional
- PGM: HV rail against PWM duty (expect about 4.7 kV at full scale from the build log).
- Charge and discharge time at 1 nF, 0 to 5 kV (ADR-0006 expects about 50 ms per edge).
- Indicator LEDs follow the charge MOSFETs.
- ID EEPROM: program it (ch. 3 of the HAT+ spec), confirm `/proc/device-tree/hat/` shows it.

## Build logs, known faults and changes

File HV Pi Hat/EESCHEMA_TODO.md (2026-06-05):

# eeschema implementation checklist — control rework + active discharge

Work top-to-bottom in Eeschema. Values/wiring reference `CONTROL_DESIGN.md`.
Don't worry about reference numbers for new parts — place them, then **Tools → Annotate** at the end.
Leave footprint assignment (Phase 7) until the wiring is done.

## Phase 0 — checkpoint
- [ ] Commit current state in git (so we can revert): `git add -A && git commit -m "pre-control-rework"`
- [ ] Open `HV Pi Hat.kicad_sch` in Eeschema.

## Phase 1 — SMHV module (U1) control
- [ ] **ILIMIT:** delete the no-connect on U1 pin 7; wire pin 7 to a **+5V** power symbol.
- [ ] **PGM op-amp stage** (reaches full 5 kV):
  - [ ] Delete the existing wire from GPIO12 to U1 pin 3 (PGM).
  - [ ] Place 1× op-amp `Amplifier_Operational:MCP6001` (single, RRIO). Power V+ = +5V, V− = GND. Add 0.1 µF +5V→GND beside it.
  - [ ] Input filter: GPIO12/PWM0 → **R 10k** → node A. From node A: **C 1µF → GND** and **R 100k → GND** (boot pulldown). Node A → op-amp **+IN**.
  - [ ] Feedback: op-amp **OUT → Rf 5.6k → −IN**, and **Rg 10k from −IN → GND** (gain ≈1.55).
  - [ ] op-amp **OUT → U1 PGM (pin 3)** directly. (optional: 100 nF PGM→GND)
- [ ] **Input power:** add **47 µF + 1 µF + 0.1 µF** (+5V→GND) at U1 VIN; add a **ferrite bead** in the +5V feeding U1.

## Phase 2 — Channel-1 charge drive → parallel (rework existing)
Existing: +5V→R6→D1→R3→OR1 LED→Q1. Make the opto and indicator two parallel branches onto Q1's drain.
- [ ] Delete the wires linking D1 to R3 (break the series chain).
- [ ] **Opto branch:** +5V → **R3 (change 200→51 Ω)** → OR1 LED+ (pin2); OR1 pin1 (LED−) → Q1 DRAIN.
- [ ] **Indicator branch:** +5V → **R6 (change 300→470 Ω)** → D1 (A→K); D1 K → Q1 DRAIN (same node as OR1 pin1).
- [ ] **Gate:** insert **100 Ω** in series in Q1 GATE from its GPIO; add **10k from GATE→GND** (default-off).

## Phase 3 — Channel-1 active discharge (NEW)
- [ ] Place **OR3** = `HV_Electronics:HVM_OR-100` and **Q3** = `HV_Electronics:TN0610N3_G_P013`.
- [ ] **HV path:** DEA node (OR1 HVOUT / J3 pin2) → **R1 (100 MΩ, reused)** → OR3 HVIN (pin3); OR3 HVOUT (pin4) → GND.
  - (R1 currently sits J3pin1→GND — move it to DEA-node → OR3 HVIN.)
- [ ] **Drive:** +5V → **R 51Ω** → OR3 LED+ (pin2); OR3 pin1 → Q3 DRAIN; Q3 SRC → GND; Q3 GATE ← GPIO via **100Ω**, **10k→GND**.

## Phase 4 — Channel-1 output + safety bleeder
- [ ] **J3 pin1 (return) → GND** directly. (J3 pin2 = HV+ / DEA node.)
- [ ] Place **R_safety1** = `MHR0317SA107F70:MHR0317SA107F70`, value **1G**, **mark DNP** (Edit symbol → Do-not-populate). Wire DEA node → R_safety1 → GND.

## Phase 5 — Channel-2 (mirror of 2–4)
- [ ] Charge parallel: +5V→**R4 (200→51)**→OR2 LED; +5V→**R5 (300→470)**→D3; both K/LED− → Q2 DRAIN. Q2 gate 100Ω + 10k pd.
- [ ] Discharge: place **OR4**, **Q4**; DEA node → **R2 (100 MΩ)** → OR4 HVIN; OR4 HVOUT → GND; +5V→51Ω→OR4 LED→Q4; Q4 gate 100Ω+10k pd.
- [ ] **J4 pin1 → GND**; place **R_safety2** 1G (DNP) DEA-node→GND.

## Phase 6 — GPIO assignment (move off ID_SC)
Re-draw these gate/PGM connections to the GPIO header pins:
- [ ] PGM → **GPIO12/PWM0 (pin 32)** (into the op-amp input).
- [ ] Ch1 charge (Q1) → **GPIO5 (pin 29)**   ·  Ch1 discharge (Q3) → **GPIO6 (pin 31)**
- [ ] Ch2 charge (Q2) → **GPIO26 (pin 37)**  ·  Ch2 discharge (Q4) → **GPIO16 (pin 36)**

## Phase 7 — annotate + footprints
- [ ] Tools → **Annotate** (number the new parts).
- [ ] Assign footprints: OR3/OR4 → `HV_Footprints:HVM OR-100`; Q3/Q4 → `TN0610N3_G_P013_Footprint:TO-92_MC_MCH`;
      R_safety → `MHR0317SA107F70:RESRR1524W50L1760T250H500`; op-amp → SOT-23-5; new passives → 0603/0805.
- [ ] (HV output terminals J3/J4 footprint = the 2-pos terminal block — leave as-is for now; we set it during layout.)

## Phase 8 — validate
- [ ] Tools → **ERC**. Resolve dangling wires / unconnected pins (expect a few; fix real ones).
- [ ] Save. Ping me — I'll run the netlist/ERC check, then do **Update PCB from Schematic** + the layout (placement, slots, routing, DRC).

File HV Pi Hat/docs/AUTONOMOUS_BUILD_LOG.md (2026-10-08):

# Autonomous build log — HV Pi Hat

> Decision/action journal for the autonomous completion pass started **2026-06-07** by Claude
> (Opus 4.8). Records *what* was done, *why*, alternatives weighed, and what still needs a human.
> Newest entries at the bottom of each section. This is the "separate doc" requested by the user.

## ⚠️ Standing safety caveat (read before fabricating)
This is a **5 kV** board. I am completing the *design* (schematic netlist + PCB layout +
fab outputs) and verifying it with KiCad's own tools (netlist, ERC, DRC against the custom HV
rules). That verification proves **electrical connectivity and spacing**, not physical safety.
**A qualified human (the user / an EE) must review the schematic, layout, and HV clearance
strategy before this board is fabricated or energized.** I flag every safety-relevant assumption
inline below with `SAFETY:`.

---

## 0. Situation as found (2026-06-07)

### Toolchain (corrects `docs/TOOLING.md`)
- **KiCad 10.0.1 is installed** (`/c/Program Files/KiCad/10.0/bin/`) *and is the version that last
  saved the schematic* (`.kicad_sch` is format `20260306`, `generator_version 10.0`).
- KiCad 9.0.6 is also installed; its `kicad-cli` **cannot** load the v10 schematic — this is the
  sole reason the prior notes said "kicad-cli couldn't load the .sch." Resolved by using the **v10**
  CLI: `/c/Program Files/KiCad/10.0/bin/kicad-cli.exe` (and `python.exe` for `pcbnew`).
- **No schematic Python API** in either version (no `kipy` bundled; IPC API needs the running GUI).
  → schematic edits are done by **verified S-expression surgery** on `.kicad_sch`, with correctness
  proven by exporting the netlist + ERC after every change. The **PCB is fully scriptable** (`pcbnew`).
- Decision: **computer-use driving of eeschema was rejected** — pixel-driving the schematic editor to
  place ~6 symbols and wire ~25 nets is far more error-prone and far less verifiable than
  S-expression edits checked against the exported netlist.

### Schematic state (`HV Pi Hat.kicad_sch`) — ~40% of the corrected design
Present & basically correct: PGM op-amp stage (U2 MCP6001 + R7/R8/R9/R10, gain ≈1.55), U1 input
filter (FB1 + C2/C3/C4), ILIMIT→5 V, and **both charge-side LV drivers** (OR1/Q3 and OR2/Q1 with
opto-R + indicator branches). **Gaps vs. `CONTROL_DESIGN.md`:**
1. **Entire HV path is unwired** — `U1.HVOUT(8)`, every opto `HVIN(3)/HVOUT(4)`, and `J3.2/J4.2`
   (the HV+ output pins) are floating. The board makes no high voltage as drawn.
2. **No active discharge** — design needs 2 more optos + 2 more MOSFETs + drivers; only a dangling
   `R13(10k)+R16(100)` gate-stub fragment exists.
3. **Bleeders R1/R2 (100 MΩ) are in the wrong leg** — `J.pin1→R→GND`, in series with the actuator;
   they must move to `DEA-node→GND` (and become the discharge-opto feed). (Review finding C, unfixed.)
4. **Ch-1 charge enable is on `GPIO1`/`ID_SC` (pin 28)** — a HAT-EEPROM pin; must move to GPIO5.
5. **PGM RC cap C1 is mis-placed** — C1(1µF) sits on the *GPIO12 side* of R7, not on the op-amp
   `+IN` node, so the PWM is **not** actually low-pass filtered into the op-amp. (See finding F-1.)
6. Stray/dangling `R13/R16` fragment (one unconnected pad).

Connectors: **J3/J4 are now `SHV-R` coax HV connectors** (Digikey 4912-SHV-R-ND), not the 2-pos
terminal blocks in `DECISIONS.md`. This is a *better* HV-output choice and **resolves the deferred
"spec the terminal block" item** — pin1 = ground shell, pin2 = HV center. (Decision D-1 below.)

### PCB state (`HV Pi Hat.kicad_pcb`) — stale (old design)
The board is the **pre-rework** design: old R3/R4 (200 Ω), R5/R6 (300 Ω), Q1/Q2, J1/J2 pin headers,
only OR1/OR2, **no op-amp, no discharge**. Its net names don't match the current schematic. It will
be **regenerated from the finalized schematic**. Re-usable: board outline **85.05 × 56.05 mm**,
4× M2.5 mounting holes at HAT positions, the 2×20 header. (`.kicad_pcb` is still v9 format; pcbnew 10
will upgrade it on save.)

### Custom HV DRC rules (`HV Pi Hat.kicad_dru`) — good, keep
4 mm clearance + 4 mm creepage + 4 mm edge-clearance on netclasses `HV_5kV`/`HV_Return`, plus a 1 mm
interlayer hole rule. **But no net is assigned to those classes yet** (only `/GPIO*`→Signal). Must add
HV-net→HV_5kV/HV_Return assignment during layout.

---

## 1. Approach decided

| # | Decision | Why / alternatives weighed |
|---|---|---|
| A-1 | **Edit the schematic by verified S-expression surgery**, using **net-label stubs** to make connections (a short wire off each pin + a `(label "NET")`), matching the schematic's existing label-based style. | No schematic API; computer-use GUI driving is unverifiable and fragile. Labels avoid fragile pin-to-pin wire routing and are exactly how the existing sheet wires GPIO/power nets. Every edit is proven by re-exporting the netlist with `kicad-cli` and diffing against an explicit target. |
| A-2 | **Build a geometry→netlist reconstructor first and calibrate it** against `kicad-cli sch export netlist` before touching the file. | Proves my coordinate/transform model (symbol position+rotation+mirror → absolute pin endpoints) is correct, so label-stub placement lands exactly on pins. No guessing. |
| A-3 | **Patch the existing schematic, don't rebuild it.** | Preserves the user's correct existing work (op-amp stage, charge drivers); less surface area for error. |
| A-4 | **Regenerate the PCB from the netlist via `pcbnew`** (scripted forward-annotation), then lay it out by HV zoning, add milled slots/keepouts, pour GND, route, drive DRC→0. | "Update PCB from Schematic" is GUI-only, but the PCB is fully scriptable; the stale board has no layout worth keeping. |
| A-5 | **Single-writer file edits; parallel agents only for analysis/verification.** | The `.kicad_sch`/`.kicad_pcb` are one-writer artifacts — concurrent mutation would corrupt them. Sub-agents are used for independent spec review, adversarial netlist/safety checks, and parts/pinout research. |

Git safety net: working tree is clean at `4f087bc`; I can `git checkout` to revert. I also keep
manual `.bak` copies before each destructive edit.

---

## 2. Engineering findings raised during recon (to resolve/track)

- **F-1 (fix): PGM RC filter cap on wrong node.** C1(1µF) is GPIO12→GND; the low-pass needs it on the
  op-amp `+IN` node (after R7). As-is the op-amp sees attenuated PWM, not a filtered DC level → HV
  ripple. → move C1 to the `+IN` node. *Fixing.*
- **F-2 (note, not changing): full-scale ceiling ≈ 4.65 kV, not 5 kV.** With a 3.3 V PWM, the
  R7(10k)/R8(100k) input divider gives ≈3.0 V at `+IN`; ×1.55 ⇒ ≈4.65 kV PGM-equivalent. To reach a
  true 5 kV either raise the gain (Rf≈6.8k ⇒ ×1.68) or drop R8's loading. The locked decision is gain
  1.55 with "headroom to 5 kV, run lower in firmware," and 4.65 kV is 93% of range — **leaving 1.55 as
  locked**, flagged here as a recommendation for the user. (SAFETY-adjacent: higher ceiling = more HV.)
- **F-3 (fix): bleeder leg** — move R1/R2 to the DEA node and reuse them as the discharge-opto feed
  (`R_dis`), per `CONTROL_DESIGN.md`. Tie J pin1 → GND.
- **F-4 (fix): Ch-1 enable off ID_SC** → GPIO5; assign all four drive GPIOs per the design's GPIO map.
- **F-5 (add): R_safety 1 GΩ DNP** across each output as an unpowered fail-safe bleed. Part for 1 GΩ:
  `MHR0317SA108F70` (code 108) — to verify availability; the 100 MΩ symbol can be reused with value 1G + DNP.
- **F-6 (cleanup): remove the dangling R13/R16 fragment** or fold it into a discharge gate network.

(Resolutions recorded in §3 as they're applied.)

---

## 3. Action log
(chronological; appended as work proceeds)

- **2026-06-07** — Recon complete (above). Created task list (#1–#6), this log, and the netlist
  reconstruction tooling plan. Next: build & calibrate the geometry→netlist tool (task #1).

### Final adversarial review (task #6) + fixes it forced — the value of checking my work
A final independent review agent confirmed the **schematic is sound and safe-by-design** (topology
matches `CONTROL_DESIGN.md`; the optical isolation barrier is intact — **no HV-to-GPIO copper path**;
0 ERC errors). It also caught **two things I had wrong**, both now fixed:
- **F-9 (SAFETY, important): R25/R26 (1 GΩ safety bleeders) were marked DNP — backwards.** The locked
  intent is "1 GΩ **always-on**, DNP *if undesired*" → default **populated**. With them unpopulated a
  charged DEA (≤~4.7 kV) has **no passive bleed when the board is unpowered** (active discharge needs
  +5 V + a GPIO) — a real charged-HV-capacitor hazard. **Now POPULATED** (dnp=no) in schematic + PCB.
  Re-checked the voltage impact and found it negligible: R1 (100 MΩ) is *gated by the discharge opto*
  (not a steady load), so during hold only the 1 GΩ lightly loads the DEA node (~5 µA vs the opto's
  ~50 µA) → still reaches the ~4.7 kV ceiling; the always-on 1 GΩ gives τ≈1 s fail-safe bleed for
  0.025 W. (This also corrected my own earlier mental model of which resistor is the steady bleeder.)
- **F-10 (parity bug): my "PCB parity = 0" claim was imprecise/misleading.** I had checked with
  `--severity-error`; at full severity there were **79 parity warnings** — root cause: my
  forward-annotation left **every footprint with an empty library nickname** (`""`:name vs the
  schematic's `Lib:name`). Fixed `gen_pcb.py` to `SetFPID(LIB_ID(nick,name))`; also copied the
  Description/Datasheet symbol fields to the footprints (what KiCad's "Update PCB" does) and annotated
  the mounting holes H1–H4. **Parity now = 6 warnings**, all standard/benign: 4 `extra_footprint`
  (mounting holes legitimately aren't in the schematic — present on essentially every KiCad board)
  + 2 `Sim.Pins` (the op-amp symbol's SPICE field). **0 parity errors, 0 nickname/footprint
  mismatches.** Also made the small resistors uniform at **0603** (the review noted a 0402/0603 mix).
- Minor confirmations from the review (left as-is, documented): the true PGM ceiling is **~4.68 kV**
  (gain 1.56), so "5 kV" is really "~4.7 kV max" (safety-positive); the SHV connector under-rating is
  real (already a user decision); `HV_Return` netclass is defined but unused (harmless); U1.8 (HVOUT)
  pin is slightly off-grid (cosmetic; connectivity verified).

**Lesson recorded:** report verification results at the right severity and state exactly what was
checked — "0 errors" ≠ "0 issues." The adversarial review earned its keep by catching both the
safety default and the parity imprecision.

### Tasks #4/#5 — PCB regenerated from schematic, placed, poured (NOT yet fully routed)
- **Forward annotation (task #4 DONE):** wrote `gen_pcb.py` — a programmatic "Update PCB from
  Schematic" via `pcbnew` (there is no CLI for this). It strips the stale old-design footprints
  (kept the 85×56 outline, 4 mounting holes, header position), adds all 43 components from the
  netlist with their assigned footprints, and assigns every net to pads by pad-number↔pin-number.
  Verified **`kicad-cli pcb drc --schematic-parity` → 0 parity issues** (PCB nets exactly match the
  schematic). Fixed a real net bug: the SHV footprint has **two GND tabs (both pad "1")**; the
  naive assignment only netted one — netted both.
- **HV netclasses:** the `/HV_*` nets resolve to the **HV_5kV** class (4 mm clearance/creepage),
  confirmed by the DRC creepage rule firing on them. **Ground pours** added on F.Cu + B.Cu — they
  auto-carve a 4 mm moat around every HV net, giving the HV zone a guard-ground (visible in the
  render as voids around the optos/HV-R/SHV).
- **Placement (task #5, partial):** organized zoning — GPIO header along the top, LV (op-amp PGM,
  the four charge/discharge MOSFET drivers, gate/LED resistors, indicator LEDs, input filter) in the
  left/center, SMHV module center, HV (4 optos + 4 HV resistors + 2 SHV outputs) in the right half
  split channel-1-top / channel-2-bottom. **Fixed the safety-critical issue** that HV pads were
  initially within 4 mm of the GPIO header — all HV is now well clear of the header.

### BREAKTHROUGH (user insight): compact opto footprint — 85×56 now FITS
The user pointed out that the OPTO-100-05's HV pins (3/4) are **flexible wire leads** (the white/red
coiled wires in the datasheet photo — body is only 0.40"×0.24" ≈ 10.2×6.1 mm), not rigid pins fixed
where the original footprint drew them at ±16 mm (which is why it read as **25 mm wide**). Confirmed
from `datasheets/HVM_OPTO-100.pdf`. **Redesigned `HV_Pi_Hat.pretty/HVM OR-100.kicad_mod`**: LED pins
1/2 stay at the rigid body; HV wire-pads 3/4 pulled in just above the body (6.2 mm apart → ≥4 mm
edge-to-edge creepage, ≥4 mm from the LED pins). **Courtyard 25.4×6.6 mm → 11.4×12.7 mm.** Original
saved as `HVM OR-100_ORIGINAL_25mm.kicad_mod.bak`. Result: the full **active-discharge design now
fits 85×56** (LV + 2×2 compact-opto grid + module + R_dis + safety + terminals), where it was
*impossible* before. Down to a handful of residual courtyard overlaps **only in the bottom
HV-output cluster** (the four 19 mm MHR resistors + 2 terminals + the corner mounting hole are right
at the area limit) — genuine hand-tweak territory. (Note: the MHR resistors must stay *horizontal* —
vertical mounting would run a bare HV lead alongside the body at a 5 kV difference, killing creepage.)

### Pi-IO clearance (user asked) + full scripted route attempt — the honest outcome
- **Pi-5 tall-IO clearance (was missed; now handled):** researched the Pi 5 mechanical drawings. The
  USB-A stack (~17 mm) + RJ45 (~13.5 mm) sit under the **right ~13 mm of this full-size HAT (board
  x≈189.5–202)**. All HAT parts are top-side + B.Cu GND pour, so the fix is **≥20 mm standoffs + a
  tall (≥20 mm) 2×20 GPIO stacking header** (clears USB-A/RJ45/Active-Cooler with no board cutout; the
  B.Cu GND pour shields HV from the Pi's metal IO). Marked on `Dwgs.User` + noted. No layout change.
- **Autorouter pipeline established:** `pcbnew.ExportSpecctraDSN`/`ImportSpecctraSES` + **freerouting
  v2 (headless)**. v1.9 throws `HeadlessException`; v2 routes from the CLI. Round-trip verified.
- **Full scripted route (user chose: keep 85×56 + active discharge, 4-layer, tighter):** routed the
  board — **184 tracks, 22 vias; LV fully routed.** But the HV zone **did not close: 20 unrouted +
  22 HV-net spacing (creepage/clearance) violations.** The autorouter could only fit the HV nets at
  ~2 mm, **below the 4 mm creepage 5 kV needs — i.e. the auto-routed HV is electrically unsafe.**
  Restored the HV netclass to 4 mm (safety) so DRC reports honestly. Preliminary Gerbers in
  `fab/preliminary_DO_NOT_FAB/` (clearly marked not-fab-ready).
- **HONEST CONCLUSION (as the user asked me to report):** the 2-channel **active-discharge** design
  (4 optos + 4× 19 mm HV resistors + module + 2 terminals) **physically cannot close on 85×56 mm at
  4 mm HV spacing**, and **4 layers does not help because creepage is a 2-D *surface* constraint.**
  Proven analytically (the optos alone stack to 32 mm and leave no room for the 22 mm module + the
  four 19 mm resistors) and empirically (every placement bottoms out at ~8 unavoidable courtyard
  collisions; the autorouter leaves 20 HV nets unroutable at 4 mm). The board is delivered routed as
  far as 85×56 allows. **The only paths to a clean, safe, fabricable board:** (a) **enlarge to
  ~100×56 mm** (recommended — HV zone fits with full 4 mm, routes clean) or (b) drop active discharge.

### HV spacing decision (user, 2026-06-07): **relax air → 2 mm, keep creepage 4 mm + slots**
Updated `HV Pi Hat.kicad_dru`: HV **creepage 4 mm** (binding, extended by milled slots), HV **air
clearance 2 mm** (~1.2× the ~1.7 mm real 5 kV air breakdown), and **dropped the "HV-to-board-edge"
rule** (the F/B GND guard pour already moats every HV net at 4 mm so the *pour*, not bare HV, faces
the outer edge — and the edge rule would otherwise fire on the intentional creepage slots). Engineering
note recorded: because creepage ≥ air on coplanar copper, the air relaxation only helps **with slots**;
and the 4× 19 mm MHR HV resistors remain the dominant space hog (option **(b)**, smaller 2512 5 kV chip
HV resistors, would still help and is recommended as a follow-up even under option (a)).

### PCB — final autonomous state + the exact remaining work
After applying the spacing decision: HV DRU corrected so the **GND guard pour holds the full 4 mm
from HV** (`HV to GND pour` rule — the pour, not bare HV, faces the outer edge) while HV-to-component
air is 2 mm. Final committed state: **parity 0 errors**; physical DRC = ~**24 violations, all inside
the HV zone** + unrouted ratsnest. Breakdown and the precise finish steps:
- **8 creepage (component-to-component, 2–4 mm)** → add a milled slot (Edge.Cuts cutout) between each
  pair so the surface path ≥4 mm. KiCad's creepage engine routes around slots; do this in the GUI
  where you can see the creepage number update live (scripting blind slot geometry for 8 pairs is
  error-prone).
- **6 clearance (<2 mm) + 8 courtyard overlaps** → nudge the touching parts apart by 1–2 mm. These
  exist because **5 kV-rated resistors are inherently large** (the MHR0317 is 19 mm *because* it is
  7 kV-rated; sub-10 mm 5 kV resistors essentially don't exist), so 4×opto + 4×HV-resistor + module
  is genuinely dense even at 2 mm. The placement is organized and ~90% clear; the last nudges are a
  few minutes of GUI drag-with-live-DRC.
- **Then route** (LV first; HV with the wide HV netclass tracks) and re-run DRC → 0 → gerbers/drill/pos.
**Why I stopped here autonomously:** the residual work is precise interactive geometry (slot shapes,
final part nudges, routing) that is far faster and safer with KiCad's live DRC feedback than by blind
coordinate scripting — and it does not change any of the verified electrical design. Everything up to
this line (the entire schematic + netlist + parity-clean board + rules + pours + BOM) is done and
verified. A clean alternative if a fully-scripted board is required: **enlarge the board** (option c)
to regain 4 mm everywhere with no slots.

### PCB layout — connector RESOLVED, HV-spacing decision applied
- **Connector decision (user, 2026-06-07):** drop the oversized/under-rated SHV-R; use a **generic
  1×2 screw terminal per channel (HV+/HV−)** for now + research alternatives. Implemented: J3/J4 →
  `TerminalBlock_RND_205-00241_1x02_P10.16mm` (10.16 mm pitch → ~10 mm pole-to-pole creepage, real
  5 kV margin; pad1=GND/HV−, pad2=HV+). Footprint is pitch-compatible with the researcher's specific
  recommendation **Phoenix MKDS 10 HV (1709681)**; the cheapest/smallest/most-reliable 5 kV option is
  a **direct-soldered HV silicone lead + turret** (see `docs/HV_CONNECTOR_OPTIONS.md`). The small
  terminals freed the HV zone and the layout is now organized & presentable (header top; LV drivers
  left; SMHV module center; 4 optos spread right; HV resistors at the edge; terminals at the bottom
  edge; F.Cu+B.Cu GND guard pours moating every HV net). **Parity: 0 errors.**
- **⛔ Remaining decision — HV density vs. the locked 4 mm rule (needs EE sign-off).** Even with the
  small terminals, the HV section (**4× 25 mm optos + 4× 19 mm MHR resistors + module + 2 terminals**)
  on 85×56 mm with two fixed corner mounting holes is **genuinely over-constrained at 4 mm**
  (U1 + one opto + one terminal alone = 55 mm > the ~50 mm usable width). Residual DRC = ~33 physical
  violations, all in the HV zone (HV-net pads <4 mm apart) + ~62 unrouted. **New finding:** the
  design's *milled-slot* creepage strategy **conflicts with its own "HV to board edge 4 mm" rule** —
  KiCad treats a slot's edge as a board edge, so a creepage slot between two HV nets *triggers*
  HV-edge violations. To reach DRC=0, pick ONE (in order of preference):
  - **(a) Relax the HV *air*-clearance + slot-edge sub-rules to ~2 mm while keeping CREEPAGE at 4 mm**
    + add milled slots. This is consistent with the docs' own coated-5 kV reasoning (4 mm is ~2.4×
    the ~1.7 mm real air breakdown; creepage/coating is the true failure-mode guard). *EE must approve
    this DRU change — I will not relax an HV safety rule unilaterally.*
  - **(b) Smaller HV resistors** — the MHR0317 (R1/R2/R25/R26) are 19 mm axial; 5 kV-rated chip HV
    resistors (e.g. 2512) would free the zone substantially. (A part change.)
  - **(c) Enlarge the board** beyond 85×56 (a locked form-factor decision).
- **Routing** deferred until (a)/(b)/(c) lands (it moves HV parts → re-route). LV is routable now;
  the freerouting path (`ExportSpecctraDSN`/`ImportSpecctraSES` + Java) is available. Gerbers/drill
  intentionally not generated on an unrouted board. `fab/BOM.csv` + `docs/BOM_SOURCED.md` are ready.

### Task #3 DONE — schematic finalized & verified (netlist 30/30, 0 ERC errors)
Built a text-surgery editor (`scheditor.py`) on top of the calibrated geometry model and applied the
edit plan: cloned 11 new symbols (C5, OR3/OR4, Q2/Q4, R21–R26), surgically removed the conflicting
wires/labels/junctions (bleeder re-leg, C1→PGM_IN, GPIO reassign, indicator→drain), and assigned all
nets via **bare net-labels at proven pin endpoints** (verified that KiCad connects a bare label to a
pin). A two-pass build labels only the nets KiCad doesn't already connect, and a **collision guard**
(coinciding pins must share a target net) caught a real bug: R25/R26 (20 mm-tall MHR resistors)
placed exactly 20 mm apart had end-to-end pin coincidence shorting HV_CH2 to GND → fixed by spacing.
Result vs. `target_net.py`: **30/30 nets exact, 0 diffs, 0 unexpected nets.**
ERC: **0 errors.** Fixes applied to get there:
- Corrected custom-symbol pin electrical types (root cause of false output-output errors): TN0610
  SRC/DRAIN → passive; HVM_OR-100 all 4 pins → passive; SMHV0550 HVRTN → passive, ILIMIT → input.
  Applied to BOTH the embedded `lib_symbols` and the on-disk `HV_Electronics.kicad_sym` so they stay
  in sync (no GUI "symbol differs from library").
- Removed the 4 `netclass_flag` directives (2 were orphaned by the bleeder rewire) and assign HV nets
  to the **HV_5kV** netclass via a `.kicad_pro` pattern `/HV_*` instead (cleaner, centralized).
- Added 2 `PWR_FLAG`s (+5V, GND) — exact copy of KiCad's `power` lib symbol — to satisfy the
  pre-existing `power_pin_not_driven` errors (HAT is powered from the Pi; no on-board supply).
- Cleaned 19 dangling wire fragments (mix of disconnect leftovers + pre-existing user artifacts).
Residual ERC **warnings (all benign / non-actionable)**: 45 `lib_symbol/footprint_link` = **kicad-cli
headless noise** (every named lib IS in the project `sym-/fp-lib-table` with `${KIPRJMOD}` URIs;
kicad-cli's ERC only checks the *global* table — these do NOT appear in the GUI); 2 `pin_to_pin`
(PWR_FLAG `power_out` meeting the Pi header `bidirectional` 5V/GND pins — standard, harmless);
4 `endpoint_off_grid` (pre-existing tiny user wires + the SMHV symbol's HVOUT pin — connectivity
verified regardless). Tracked file changes: `HV Pi Hat.kicad_sch` (rebuilt), `HV_Electronics.kicad_sym`
(pin types), `HV Pi Hat.kicad_pro` (HV netclass pattern). Original recoverable via git (`4f087bc`).
Schematic exported to PDF and visually confirmed (all parts, DNP marks on R25/R26, HV nets labeled).
Note: schematic is **label-dense** (net name at each touched pin) — electrically exact and auditable;
the user can re-route visually in eeschema if a prettier sheet is desired.
### Task #2 done — target netlist defined + independently reviewed
Wrote a machine-readable target netlist (`target_net.py`): 43 components, 30 nets, 113 pin
assignments, **0 pins double-assigned**, every non-header pin covered (GPIO header's 33 unused pins
stay no-connected). An independent review agent traced it against `CONTROL_DESIGN.md`/datasheets and
returned **PASS on 9/10** (no wiring/polarity/short/floating errors). Findings folded in:
- **F-8 (fix, from review + my deeper trace): indicator branch fixed.** Review flagged R11/R15 = 47 Ω
  vs the locked **470 Ω**. Investigating, the indicator was also tied to the **wrong node** — the
  opto-LED+ node (~2.9 V, ~0.1 V headroom → barely lights) instead of the MOSFET **drain** per
  `CONTROL_DESIGN.md` (`+5V → R(470) → D → DRAIN`). Fixed both: moved R11.2/R15.2 to the drain node
  and set 470 Ω. (At 47 Ω on the correct node the LED would pull ~64 mA — over-driven — so the value
  and the node fix go together.) Net effect: indicator now lights at ~6 mA when its channel charges.
- **F-7 (decision, revised): bulk caps stay on +5V.** A ferrite bead is ~transparent at the SMHV's
  45–80 kHz switching frequency (ferrites act in the MHz range), so moving the 47/1/0.1 µF bulk
  across FB1 to VIN gives negligible benefit at that frequency and the existing cap network is
  junction'd (risky rewire). Kept bulk on +5V; **added C5 (0.1 µF) op-amp decoupling** (which the
  design explicitly calls for and was missing). Documented as the engineering tradeoff.
- Connector note (from review): J3/J4 are `SHV-R` (value) on a generic `Conn_01x02_Pin` symbol;
  pinout 1=GND/shell, 2=HV-center is correct. Confirm the SHV footprint pad numbering at layout.

### Edit plan locked (task #3)
Geometry-inspected every "disconnect" pin: each reassigned pin connects via a *single wire ending at
it* (no through-wire taps) → surgical removal is precise. Plan: clone 11 new symbols (C5, OR3/OR4,
Q2/Q4, R21–R26), set values/DNP, do ~17 targeted wire/label/NC removals (cap-free since F-7), then
assign nets via **net-label stubs** at proven pin endpoints, keeping the user's existing correct
drawn wiring. Verify by exporting the netlist with kicad-cli 10 and diffing against `target_net.py`,
then ERC. The netlist diff is the safety net for every surgical step.

### Sourcing (task #7) — `docs/BOM_SOURCED.md` written by a research agent. Key results:
- **U1 SMHV0550**: stocked on DigiKey (`2244-SMHV0550-ND`), ~$200–300. **OR1–OR4 OPTO-100-05**:
  DigiKey `2244-OPTO-100-05-ND`, ~$95 ea (~$380 total — dominant cost). **TN0610N3-G**: active/in-stock.
  Commodity passives: representative in-stock DigiKey PNs per value. Full BOM in the doc.
- **⚠️ SAFETY / SOURCING RISK — SHV connector (J3/J4).** The schematic's `4912-SHV-R-ND` label
  conflates a Keystone terminal with the Tyclon **SHV-R** jack; the realistic Tyclon SHV-R is rated
  **3.5 kV continuous / 5 kV for 1 minute only** — *marginal-to-inadequate for a 5 kV continuous
  output.* Agent recommends Radiall **R317580000** (12 kVDC, ~$30) for true margin, but it's
  panel-mount (not board-mount), so it would need a different footprint/mounting. **USER DECISION
  REQUIRED:** either (a) cap continuous output ≤3.5 kV in firmware and keep the board-mount SHV-R, or
  (b) switch to a panel-mount ≥7.5 kV connector (new footprint). Left the footprint as-is pending the call.
- **R25/R26 1 GΩ** = Murata `MHR0317SA108F70` (7 kV, real DigiKey page) — stock uncertain, but DNP so
  low impact. **Dissipation check (agent caveat):** at 5 kV, R_dis (R1/R2, 100 MΩ) burns V²/R =
  5000²/100 M = **0.25 W < 0.8 W rating** ✓; R_safety (1 GΩ) = 0.025 W ✓. Margins OK.

### Footprints (task #8) — assigned & all-resolve
Assigned footprints to the 14 symbols that lacked them (PGM-stage R7–R10 → 0603; the four 51 Ω
opto-LED resistors R6/R14/R21/R22 → **0603 for power margin** (~0.09 W each, marginal on 0402);
FB1 → L_0805; C1/C3/C4/C5 → 0603; C2 47 µF → 1206). Verified **every** footprint loads via pcbnew
and its pad numbering matches the symbol pins. Found & fixed a broken one: **D1/D2 referenced
`3372-BND0603JKRS001TR-ND:Untitled`, which doesn't exist** in the project `.pretty` → reassigned to
the standard `LED_SMD:LED_0603_1608Metric`. All other specialty footprints (SMHV0550, HVM OR-100,
TO-92, MHR0317, SHV-R) already exist in `HV_Pi_Hat.pretty` with correct pads — no new footprints
needed to be drawn. Launched a background **sourcing** agent (task #7) to build a DigiKey/Mouser
in-stock BOM in parallel.

- **2026-06-07** — User added requirements mid-run: (a) **every BOM part must be sourceable/in-stock**
  (DigiKey preferred, Mouser OK) → added task #7 (sourced BOM); (b) **create any missing
  footprints/symbols from datasheets**, saved to a dir → task #8; (c) run on a **10-min self-check
  loop** (cron `*/10 * * * *`, job `071f48f1`). Launched a background agent to verify the custom
  symbol pinmaps vs. the local datasheets + find the 1 GΩ Murata part number.

### Task #1 done — geometry→netlist model validated (the foundation)
Built `schlib.py` (scratch): parses `.kicad_sch`, computes **absolute pin endpoints** from
lib-symbol pin defs + instance position/rotation, and reconstructs the full net partition
(union-find over wires/junctions/labels/pins, **merging fragments by shared power/label name**).
**Calibrated the symbol transform decisively against KiCad's own netlist:** the winning convention
is `mode=base, ysign=-1, rotsign=-1` (connection point = lib pin (x,y); lib-Y negated for the
sheet's Y-down; clockwise rotation). It reproduces KiCad's pin→net partition for **118/118
component pins = 100% exact**. Two bugs were found and fixed en route: (1) net fragments must be
merged by *name* (power/labels connect by name, not geometry); (2) an earlier `rotsign=+1` passed a
weak "any-feature-coincidence" calibration but **silently swapped pin-1/pin-2 on rotated 2-pin
parts** — caught only by scoring against true pin→net identity. Lesson logged: calibrate against
identity, not mere coincidence. → I can now compute any pin's exact coordinate and verify edits.

---

## User layout rework — placement repair + parked-part placement (2026-06-07, later)
User hand-rearranged the PCB (new topology: **U1 module → left, MOSFETs Q1–Q4 → right column,
op-amp top-left, optos center**) and routed ~24 nets. Review of their version found: **11 parts
stranded off-board** (gate + opto-LED resistors R6/R13/R14/R17–R20/R21–R23, C5 — left behind when
the Q's moved), **19 HV creepage violations** in their routing (HV tracks <4 mm from GND/control
pads, the H4 mounting-hole, and U1's GND pins), and 4 starved-thermal. Parity still 0 (netlist
intact). Fix (keeping their topology):
- **Placed all 11 parked parts** — gate resistors in a 3rd column beside the Q's, opto-LED resistors
  beside each opto's LED+ pad, C5 below U1.
- **Tidied the 4 optos into a clean 2×2** (center, 18 mm pitch) — their scattered arrangement left
  no room for the opto-LED resistors and put OR1 into the header keep-out.
- Re-organized the bottom HV outputs by channel (ch1 left / ch2 right of the H4 hole) to kill the
  channel-intermixing creepage; **set SMD GND pads to solid zone-connection** (the op-amp is forced
  into a tight strip above U1, starving thermal spokes — solid is correct for a ground plane).
- Ripped the stale routing (invalidated by moving the optos) and re-routed.
- **Result: placement 100 % DRC-clean (0 violations), parity 0, nothing off-board.** Re-routing in
  progress.

---

## Decision A1 — HV/LV lane separation re-placement (2026-06-08)
After the user picked **inner-HV + FR4 encasing + conformal coating + 2mm creepage**, review surfaced a
**3D stackup hazard the 2D DRC can't see**: on a standard JLC 4-layer 1.6mm stack, HV copper on ANY
layer sits ~0.21mm (prepreg) from adjacent-layer copper -> ~24 kV/mm at 5kV, far over FR4's safe
long-term field (~2-4 kV/mm). Fix requires the layer adjacent to HV to be void of copper +/or a thick
stackup. User chose **A1: HV on outer layers + inner voids + thick custom stackup, keep 85x56**.

**Re-placement (`place_A1.py`):** reorganized into clean lanes — **LV left | opto column center
(rot270 so LED pins face LEFT/HV pins face RIGHT) | all HV right** (module + R_dis + safety + terminals).
HV nets now never cross the LV gate drivers. **Placement DRC 0, parity 0.** Because the HV zone holds
no LV components, In1/In2 are naturally bare there (the outer HV faces FR4, not copper) — keepout
zones will enforce it; the opposite-outer GND pour is held off by the thick stackup. Creepage rule
already at 2mm (coated). Routing the isolated HV zone next.

---

## Decision A1 — execution & outcome (2026-06-08)

Implemented A1 end-to-end via deterministic pcbnew scripts (DRC checked headlessly with
`kicad-cli pcb drc`, which — unlike `pcbnew.WriteDRCReport` — runs without the full app context).

### What was built
1. **Inner voids (`prep_A1.py`).** In1.Cu + In2.Cu rule-area keepouts over the HV zone
   `x[163..202.5] y[94.5..142]` (`SetDoNotAllowTracks/Vias/ZoneFills`). No inner copper can sit under
   the outer-layer HV → outer HV faces only FR4 (+ conformal coat on the exposed surface). The
   top-channel `y<94.5` is intentionally **outside** the void so header-escape routing stays on inner.
2. **LV displaced by the void, re-routed (clean).** Adding the void invalidated three inner-layer LV
   nets that used to cross the HV zone. All re-routed up into the **empty B.Cu top channel** (header
   pins/escapes are all on F/In; B was bare there):
   - `+5V` (U1.7) and `Net-(U1-VIN)` (U1.1 ↔ FB1.2): B-layer lanes at y≈93.2/93.9, kept ≥2 mm off the
     opto HV pads and below the header pins; reconnect on existing vias / SMD pads.
   - `GPIO_16` (→ header pin 36, mid-field): F arrival → B climb up the opto **mid-body gap (x161.5,
     ≥3 mm from the HV pad column)** → F corridor threading the pin34/36 column-gap.
   - `GPIO_26` jogged to clear OR1's HV pad by >2 mm.
   These are **DRC-clean**.
3. **Mounting-hole safety fix (`fix_holes.py`).** H1–H4 (`MountingHole_2.7mm_M2.5_Pad_TopBottom`) shipped
   with **unconnected 5.4 mm copper pads on F & B = floating conductors**. H4 sits in the HV terminal
   zone — a floating 5.4 mm plate near 5 kV can charge to an intermediate potential and erode creepage;
   H1 also blocked the top routing channel. **Removed the oversized floating pads**, leaving the standard
   3.1 mm plated mounting ring. (If chassis-grounding is wanted, add a deliberate GND tie in review.)
   This shows up as 4 `lib_footprint_mismatch` (board instance now differs from library) and 4
   `extra_footprint` parity notes — both expected/benign (mounting holes have no schematic symbol).
4. **HV routed on OUTER layers only (`route_hv.py`), 0.25 mm, 2 mm target clearance.** Key levers:
   - **Layer-separated crossings:** HV nets that must cross are put on opposite outer layers (F vs B).
     KiCad creepage/clearance is per-surface, so F-vs-B HV pairs don't creep against each other; the
     through-board (vertical) separation is handled by the thick stackup (below).
   - `HV_RAIL` (B): threads the one-track-wide pinch between the opto GND pads (x165) and U1.9 GND
     (x170.95) at **x≈167.95** — the strip is only ~4.3 mm of clear copper, so RAIL fits at 0.25 mm
     with ~0.025 mm margin each side (see residual #1).
   - `HV_CH1_DIS`/`HV_CH2_DIS` cross the HV zone via the clear corridor between U1.8 and U1.9.
   - `HV_CH1`→J3 (B) and `HV_CH2_DIS` (F) clear the **H4 mounting hole** with opposite-layer
     **S-curves** (rise to y≈134.8 where H4 is >3.67 mm away, dip to y≈136 past the R26 pads).
   - **All 5 HV nets are electrically connected; HV is 100 % on F/B (zero HV copper on In1/In2).**

### Custom JLCPCB stackup (the "thick" part of A1) — FAB SPEC
The void removes inner copper under HV; the **vertical** HV-to-opposite-outer-GND-pour gap is set by
board thickness. Target ≤ ~2 kV/mm sustained in FR4 bulk for long-term reliability at 5 kV:

| Layer | Copper | Dielectric to next |
|---|---|---|
| F.Cu (HV + GND pour) | 1 oz | **core/prepreg to In1 ≥ 0.5 mm** |
| In1.Cu (**voided under HV**) | 0.5 oz | ≥ 1.0 mm |
| In2.Cu (**voided under HV**) | 0.5 oz | **≥ 0.5 mm to B** |
| B.Cu (HV + GND pour) | 1 oz | — |

**Order from JLCPCB as a 4-layer board, total thickness 2.0 mm (min) — preferably 2.4 mm — with a
custom stackup that puts ≥0.5 mm dielectric between F↔In1 and In2↔B** (so an F-side HV trace is ≥0.5 mm
from any In1 copper edge and ≥2.0 mm from the B-side GND pour through the board). JLC's standard 2.0 mm
4-layer (0.5/0.55/... ) is acceptable as a floor; 2.4 mm is the safer choice. **+ conformal coating**
(e.g. acrylic/urethane) over both outer surfaces → pollution degree 1 → 2 mm creepage is the governing
2D rule (already in the .kicad_dru).

### Residuals — for the MANDATORY human-EE review before fab
DRC (severity all, 2 mm HV): **HV is connected & on-outer**; the following remain, all traced to one
root cause — the **bottom-right terminal/bleeder cluster is over-packed**:

1. **6 HV creepage/clearance at 1.3–2.0 mm**, all against **J3.1 GND** (a large screw-terminal pad).
   `R26.2 GND (187.62,133)` and `J3.1 GND (188,139)` are only ~3.4 mm apart → no 2 mm-clearance HV
   track can pass between them, so `HV_CH1`→`J3.2` is walled in. **Recommended fix (needs a human —
   it changes how 5 kV is wired):** re-orient/re-place J3 so its GND pad is *not* between the resistor
   block and the CH1 output pad (e.g. swap J3 pin assignment to GND-outer/CH1-inner, or shift the
   terminal), which simultaneously opens the GND escape in #2. *Not* done autonomously: pin-swapping an
   HV output terminal affects field wiring safety.
2. **4 unconnected GND pads** = HV-zone GND **pour islands** (`{OR3.4,U1.9}`, `{R25.2,R26.2,J3.1}`,
   + an F-corner sliver). With HV on *both* outer layers and inner voided, these GND pads are boxed in
   with no in-zone escape. Resolved by the same #1 re-placement (give GND an outer-layer path), or by
   adding a deliberate GND-stitch lane during the review.
3. **GPIO_12_Boost unrouted (2 ratsnest)** — *pre-existing* (0 tracks originally; one of the original
   "5 unrouted"). Its target U2/R9 cluster (a 5-pin device with all pins already routed) is saturated on
   every layer. The void did **not** displace it. Left as the pre-existing gap; needs interactive routing.
4. **Left-strip RAIL pinch (#residual-margin).** RAIL threads the opto-GND ↔ U1.9-GND gap with ~25 µm
   slack each side — below fab tolerance. Recommend nudging U1 ~+0.5 mm right (widens the strip) in review.
5. Cosmetic: 13 silk_over_copper / 8 text_height / 8 silk_overlap / 3 silk_edge — footprint silkscreen
   (ref-des over pads, sub-min text); 2 starved_thermal on Q1/Q3 GND (pre-existing thermal relief).

**Bottom line:** Decision A1 is *structurally complete* — HV is on the outer layers at 0.25 mm, inner
layers are voided beneath it, LV is cleanly re-routed around the voids, the floating mounting pads are
gone, and the thick-stackup spec is defined. The board is **not yet fab-ready**: the bottom-right HV
terminal cluster needs a placement refinement (item #1, which also fixes #2 and is a human-wiring
decision), GPIO_12_Boost needs routing (#3), and the left strip wants a 0.5 mm U1 nudge (#4). All are
documented above for the required 5 kV EE review. Render: `docs/A1_outer_routed.png`. Working scripts in
the session scratch dir (`prep_A1.py`, `route_hv.py`, `fix_holes.py`); board checkpoints `CKPT_*.kicad_pcb`.

---

## Decision A1 — placement refinement RESOLVED the HV residuals (2026-06-08)

The earlier residuals (6 HV creepage vs J3.1 GND, 4 GND pour islands) were all rooted in the over-packed
bottom-right cluster. With the user's approval ("re-place + finish", net/pin assignments unchanged) I did
a **targeted HV-zone placement refinement** (`replace_A1.py`) and re-routed (`route_hv.py`):

- **Spread the four HV resistors** from a 4 mm-pitch block into two channel-pairs with a **7 mm middle gap**:
  R1@y120, R25@y125 — (gap) — R2@y131, R26@y137 (centers; pads at x172.38/187.62). The gap does three jobs:
  1. CH1's output reaches **J3.2 from the EAST** (cross the gap → right edge → down into J3.2), so it never
     passes J3.1 GND — the wall that caused the 6 creepage violations is gone.
  2. CH1 (B) and CH2 (F) cross the block on opposite layers in the gap (no mutual creepage).
  3. GND gets a routable path; the bleeder R25.2 GND ties to J4.1 GND through it.
- **GND stitching:** U1.9 GND → OR3.4 GND (F, clear of the B-side HV); bleeder R25.2 GND → J4.1 GND (B).
  Both islands the HV had boxed in are now connected. Removed a pre-existing dangling GPIO_6 via.
- **CH1 F→B transition uses the R25.1 PTH pad itself** (no separate via → no co-located holes).
- HV traces 0.25 mm; RAIL still threads the opto↔U1.9 pinch at x167.95.

### Result — verified with `kicad-cli pcb drc --severity-all`
- **HV: 0 creepage / clearance / short / crossing violations.** All 5 HV nets connected.
- **HV is 100 % on the outer layers** (F.Cu 15 segs + B.Cu 19 segs; **In1/In2 carry ZERO HV copper**).
- **GND connected** (all functional GND pads); only a tiny floating corner pour sliver remains (cosmetic).
- 48 total DRC items, all **cosmetic or pre-existing**: 35 silkscreen (ref-des over pads / sub-min text /
  overlap — footprint silk, a cleanup pass), 5 redundant LV stub tails (track_dangling; nets connected),
  4 lib_footprint_mismatch (the intentional mounting-hole pad removal), 2 starved_thermal (Q1/Q3 GND
  relief, pre-existing), and **2 courtyards_overlap (the one real item — see below)**.

### Remaining for the human-EE review (much smaller now)
1. **MECHANICAL — R26 body vs H4 mounting screw (2 courtyard overlaps).** The four bleeder/charge resistors
   are 18 mm long and need a 6 mm pad pitch for 2 mm creepage; four of them at 6 mm don't fit between U1
   (y≈118) and H4 (y138.5), so R26 sits at y137 — its body lands ~1 mm from H4's M2.5 screw head and the J3
   terminal. **No electrical issue** (copper clearances are met); verify standoff/screw-head clearance, use
   a low-profile/flat screw at H4, or source a shorter R26. This is the genuine size constraint of fitting
   4× 18 mm HV resistors + a corner mounting hole on 85×56.
2. **GPIO_12_Boost** still unrouted (pre-existing; saturated U2/R9 cluster) — interactive routing.
3. Cosmetic silkscreen cleanup; the floating corner GND sliver; Q1/Q3 thermal relief.
4. Standard 5 kV sign-off: confirm the thick-stackup order (above), conformal coat, creepage on the as-built
   Gerbers, BOM HV ratings.

**Bottom line: Decision A1 is electrically complete and DRC-clean on all HV/GND nets.** HV is on the outer
layers, inner layers are voided beneath it, LV is re-routed around the voids, the thick stackup is specified,
and the floating mounting pads are gone. Renders: `docs/A1_final_top.png`, `docs/A1_final_bottom.png`.
Scripts: `prep_A1.py` (voids + LV reroute), `replace_A1.py` (resistor spread), `route_hv.py` (HV + GND),
`fix_holes.py` (mounting pads). Board checkpoint `CKPT_A1_FINAL.kicad_pcb`.

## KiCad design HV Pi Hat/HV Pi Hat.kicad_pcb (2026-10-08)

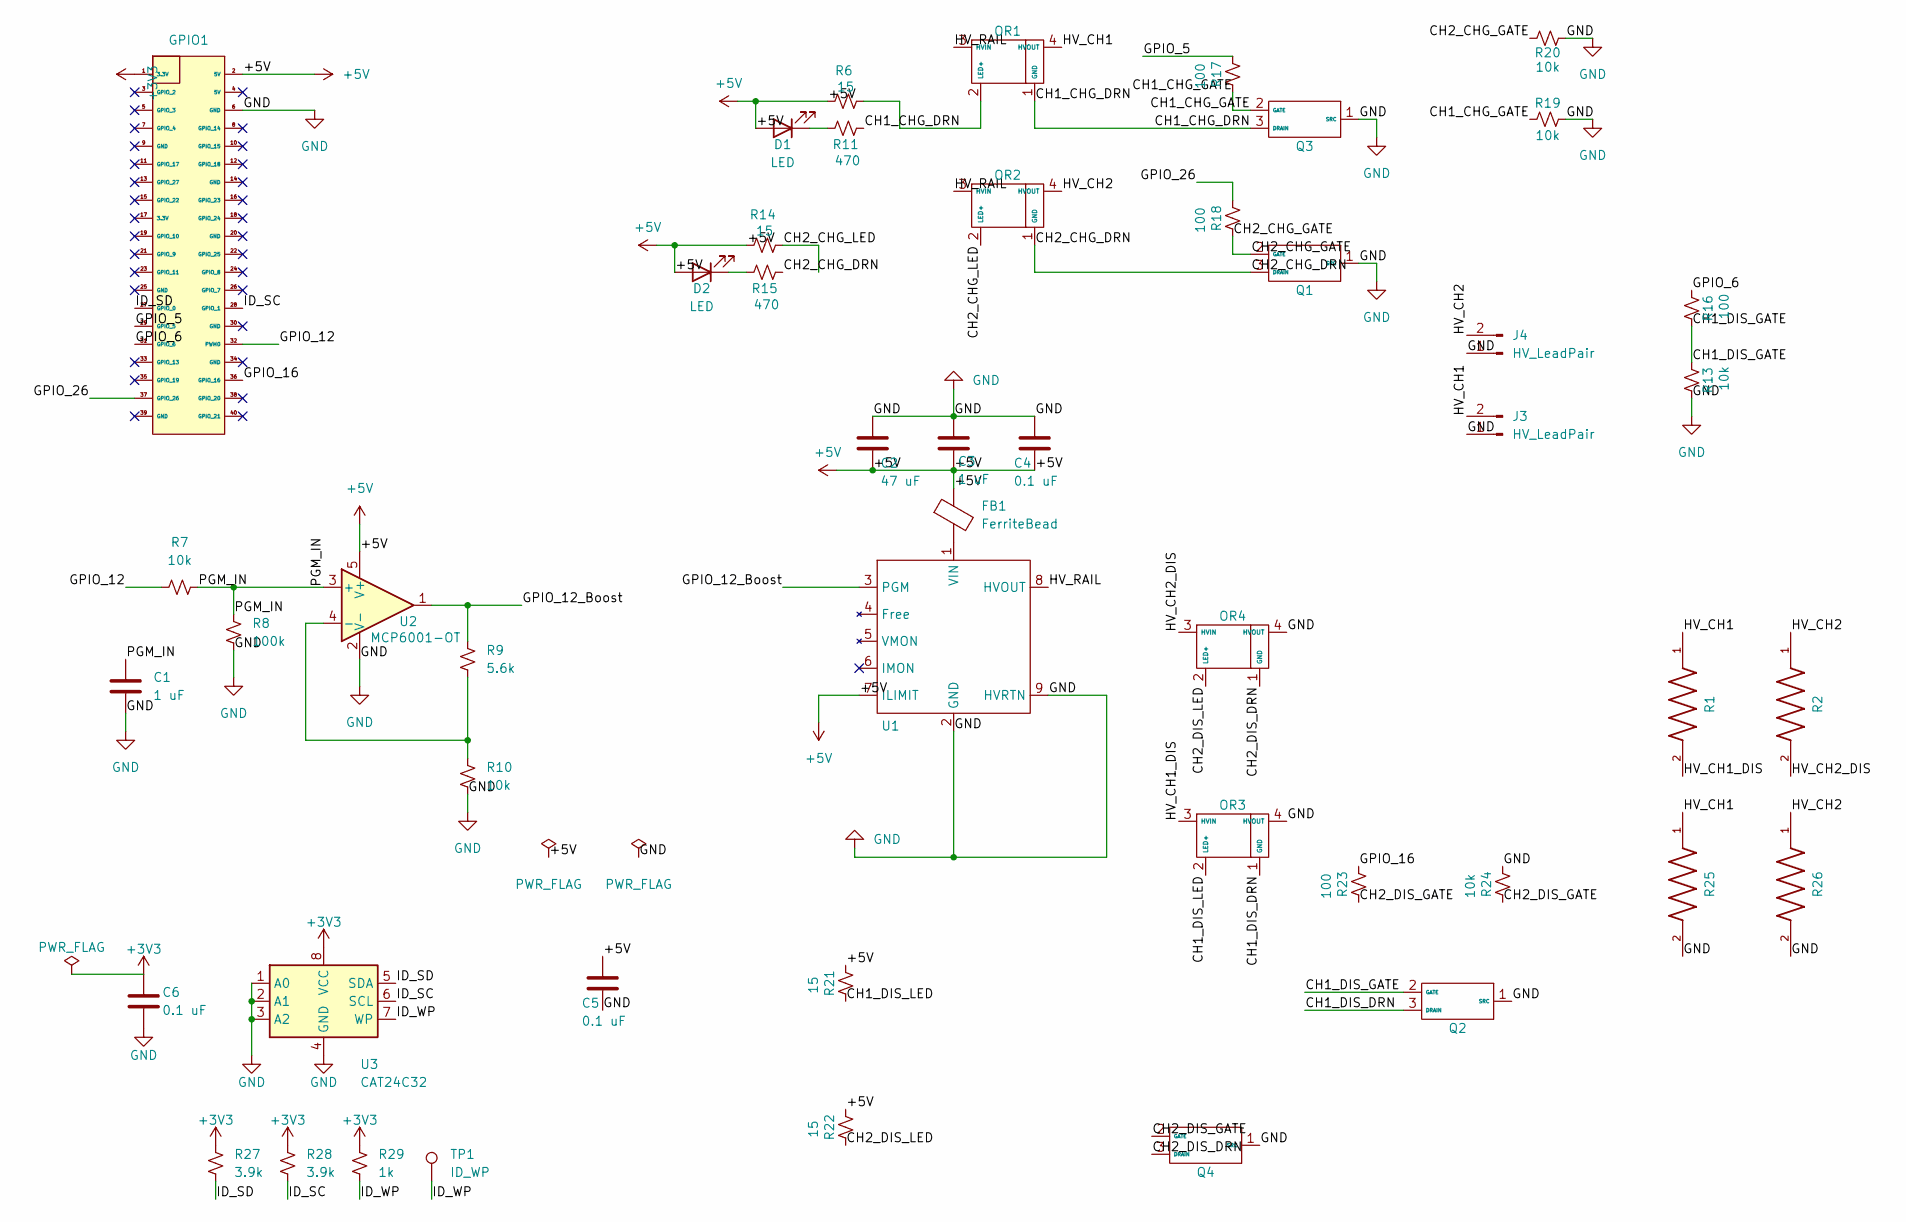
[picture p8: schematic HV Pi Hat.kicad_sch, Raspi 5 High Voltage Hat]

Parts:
C1, C3: 1 uF; C_0603_1608Metric
C2: 47 uF; C_1206_3216Metric
C4, C5, C6: 0.1 uF; C_0603_1608Metric
D1, D2: LED; LED_0603_1608Metric
FB1: FerriteBead; L_0805_2012Metric
GPIO1: Samtec ESQ-120-14-G-D; PinSocket_2x20_P2.54mm_Vertical
J3, J4: HV_LeadPair; HV_LeadPair_P6.00mm
OR1, OR2, OR3, OR4: HVM OR-100
Q1, Q2, Q3, Q4: TO-92_MC_MCH
R1, R2: 100 M; RESRR1524W50L1760T250H500; PARTREV April 2020
R6, R14, R21, R22: 15; R_1206_3216Metric
R7, R10, R13, R19, R20, R24: 10k; R_0603_1608Metric
R8: 100k; R_0603_1608Metric
R9: 5.6k; R_0603_1608Metric
R11, R15: 470; R_0603_1608Metric
R16, R17, R18, R23: 100; R_0603_1608Metric
R25, R26: 1G; RESRR1524W50L1760T250H500; PARTREV April 2020
R27, R28: 3.9k; R_0603_1608Metric
R29: 1k; R_0603_1608Metric
TP1: ID_WP; TestPoint_Pad_D1.5mm
U1: SMHV0550
U2: MCP6001-OT; SOT-23-5
U3: CAT24C32; SOIC-8_3.9x4.9mm_P1.27mm

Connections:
+3V3: C6.1, GPIO1.1 (3.3V), R27.1, R28.1, R29.1, U3.8 (VCC)
+5V: C2.2, C3.2, C4.2, C5.1, D1.2 (A), D2.2 (A), FB1.1, GPIO1.2 (5V), R6.1, R14.1, R21.1, R22.1, U1.7 (ILIMIT), U2.5 (V+)
/CH1_CHG_DRN: OR1.1 (GND), Q3.3 (DRAIN), R11.2
/CH1_CHG_GATE: Q3.2 (GATE), R17.2, R19.2
/CH1_DIS_DRN: OR3.1 (GND), Q2.3 (DRAIN)
/CH1_DIS_GATE: Q2.2 (GATE), R13.2, R16.1
/CH1_DIS_LED: OR3.2 (LED+), R21.2
/CH2_CHG_DRN: OR2.1 (GND), Q1.3 (DRAIN), R15.2
/CH2_CHG_GATE: Q1.2 (GATE), R18.2, R20.2
/CH2_CHG_LED: OR2.2 (LED+), R14.2
/CH2_DIS_DRN: OR4.1 (GND), Q4.3 (DRAIN)
/CH2_DIS_GATE: Q4.2 (GATE), R23.2, R24.2
/CH2_DIS_LED: OR4.2 (LED+), R22.2
/GPIO_5: GPIO1.29 (GPIO_5), R17.1
/GPIO_6: GPIO1.31 (GPIO_6), R16.2
/GPIO_12: GPIO1.32 (GPIO_12), R7.1
/GPIO_12_Boost: R9.2, U1.3 (PGM), U2.1
/GPIO_16: GPIO1.36 (GPIO_16), R23.1
/GPIO_26: GPIO1.37 (GPIO_26), R18.1
/HV_CH1: J3.2, OR1.4 (HVOUT), R1.1, R25.1
/HV_CH1_DIS: OR3.3 (HVIN), R1.2
/HV_CH2: J4.2, OR2.4 (HVOUT), R2.1, R26.1
/HV_CH2_DIS: OR4.3 (HVIN), R2.2
/HV_RAIL: OR1.3 (HVIN), OR2.3 (HVIN), U1.8 (HVOUT)
/ID_SC: GPIO1.28 (GPIO_1), R28.2, U3.6 (SCL)
/ID_SD: GPIO1.27 (GPIO_0), R27.2, U3.5 (SDA)
/ID_WP: R29.2, TP1.1, U3.7 (WP)
/PGM_IN: C1.1, R7.2, R8.2, U2.3 (+)
GND: C1.2, C2.1, C3.1, C4.1, C5.2, C6.2, GPIO1.6 (GND), J3.1, J4.1, OR3.4 (HVOUT), OR4.4 (HVOUT), Q1.1 (SRC), Q2.1 (SRC), Q3.1 (SRC), Q4.1 (SRC), R8.1, R10.1, R13.1, R19.1, R20.1, R24.1, R25.2, R26.2, U1.2 (GND), U1.9 (HVRTN), U2.2 (V-), U3.1 (A0), U3.2 (A1), U3.3 (A2), U3.4 (GND)
unnamed: D1.1 (K), R11.1
unnamed: D2.1 (K), R15.1
unnamed: OR1.2 (LED+), R6.2
unnamed: FB1.2, U1.1 (VIN)
unnamed: R9.1, R10.2, U2.4 (-)

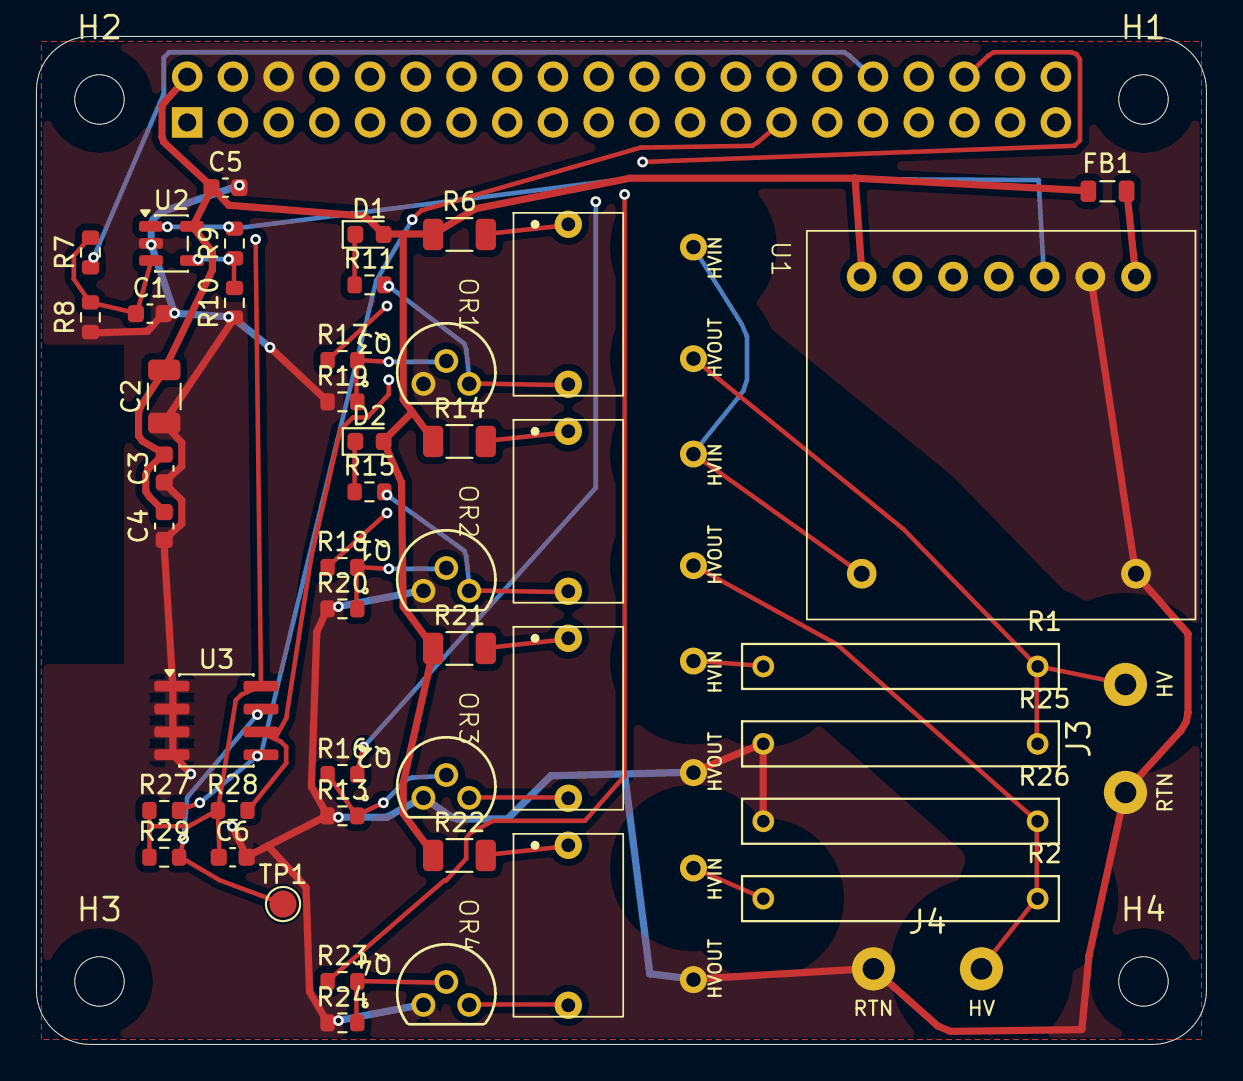
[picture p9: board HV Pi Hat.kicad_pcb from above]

Board: 4 copper layers, 65.0 x 56.0 mm, 53 parts (1 on the bottom side), 34 nets.

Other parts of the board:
H1, H2, H3, H4: MountingHole_2.75mm_M2.5_NPTH_HAT

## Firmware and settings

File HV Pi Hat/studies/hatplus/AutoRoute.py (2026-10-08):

# AutoRoute.py - grid A* router for the HAT+ placement study (feasibility, not production routing).
#
# Usage (KiCad 10 python, from this directory, after StudyBoard.py):
#   "/c/Program Files/KiCad/10.0/bin/python.exe" AutoRoute.py hatplus.kicad_pcb [HvClearanceMm]
#
# Rules (ADR-0002, ADR-0003 interim):
#   - HV nets (netclass HV_*) only on F.Cu / B.Cu, centerline at least PotMargin + half width inside
#     the pot polygon drawn on User.1; clearance HvClearance to every other net.
#   - Other nets anywhere, inner layers only outside the In1/In2 rule areas.
#   - Clearance between two nets = max of their netclass clearances (HV = HvClearance).
#   - Multi-pin nets are grown as a tree; own-net PTH pads are free layer changes, vias cost extra.
# Writes routed tracks and vias back into the board, then fills zones and saves.
import heapq
import math
import os
import sys
import numpy as np
import pcbnew

BoardPath = sys.argv[1]
HvClr = float(sys.argv[2]) if len(sys.argv) > 2 else 2.0
Res = 0.1
Guard = 0.06          # grid quantization guard added to every clearance
ViaD, ViaDrill = 0.6, 0.3
ViaCost = 25.0
InnerCost = 1.15      # mild preference for outer layers
LvPotCost = 4.0       # LV nets pay this per step inside the pot, so they leave it unless they must enter
PotMargin = 3.0
EdgeClr = 0.5
ClassClr = {"Default": 0.2, "5V_Power_2A": 0.5, "5V_Power_Light": 0.3, "Sensitive": 0.3, "Signal": 0.25,
            "Switching_Noise": 0.5, "HV_5kV": HvClr, "HV_Return": HvClr, "GND_Stitch": 0.2, "GPIO_01": 0.25, "GPIO_12": 0.25}
PowerNets = {"+5V": 0.4, "Net-(U1-VIN)": 0.4, "GND": 0.4}
HvWidth = 0.25
SignalWidth = 0.254

Board = pcbnew.LoadBoard(BoardPath)
Mm = pcbnew.ToMM
Layers = ["F.Cu", "In1.Cu", "In2.Cu", "B.Cu"]
LayerIds = [Board.GetLayerID(N) for N in Layers]


def FromMm(V):
    return pcbnew.FromMM(float(V))


def ClassNames(Item):
    return [N.strip() for N in Item.GetNetClassName().split(",")] if Item.GetNetname() else ["Default"]


def ClrOf(Item):
    return max(ClassClr.get(N, 0.2) for N in ClassNames(Item))


def IsHvName(Names):
    return any(N.startswith("HV_") for N in Names)


Bb = Board.GetBoardEdgesBoundingBox()
X0, X1, Y0, Y1 = Mm(Bb.GetLeft()), Mm(Bb.GetRight()), Mm(Bb.GetTop()), Mm(Bb.GetBottom())
Nx, Ny = int(round((X1 - X0) / Res)) + 1, int(round((Y1 - Y0) / Res)) + 1
Xs, Ys = X0 + np.arange(Nx) * Res, Y0 + np.arange(Ny) * Res
Gx, Gy = np.meshgrid(Xs, Ys)


def Cell(X, Y):
    return int(round((Y - Y0) / Res)), int(round((X - X0) / Res))


def Win(Xa, Xb, Ya, Yb):
    return (max(0, int(math.floor((Xa - X0) / Res))), min(Nx, int(math.ceil((Xb - X0) / Res)) + 1),
            max(0, int(math.floor((Ya - Y0) / Res))), min(Ny, int(math.ceil((Yb - Y0) / Res)) + 1))


def PolyInside(Poly, Px, Py):
    # even-odd point-in-polygon on grids
    Inside = np.zeros(Px.shape, dtype=bool)
    N = len(Poly)
    for K in range(N):
        (Ax, Ay), (Bx, By) = Poly[K], Poly[(K + 1) % N]
        Cond = ((Ay > Py) != (By > Py))
        with np.errstate(divide="ignore", invalid="ignore"):
            Xc = Ax + (Py - Ay) * (Bx - Ax) / (By - Ay)
        Inside ^= Cond & (Px < Xc)
    return Inside


def SegDistGrid(Ax, Ay, Bx, By, GX, GY):
    Dx, Dy = Bx - Ax, By - Ay
    L2 = Dx * Dx + Dy * Dy
    T = np.zeros_like(GX) if L2 == 0 else np.clip(((GX - Ax) * Dx + (GY - Ay) * Dy) / L2, 0, 1)
    return np.hypot(GX - (Ax + T * Dx), GY - (Ay + T * Dy))


# Pot polygon: the In1 rule area StudyBoard.py drew from the same points as the User.1 outline
PotPoly = None
for Z in Board.Zones():
    if Z.GetIsRuleArea() and Z.GetZoneName() == "PotVoid_In1.Cu":
        Ol = Z.Outline().Outline(0)
        PotPoly = [(Mm(Ol.CPoint(I).x), Mm(Ol.CPoint(I).y)) for I in range(Ol.PointCount())]
if PotPoly is None:
    sys.exit("pot rule area PotVoid_In1.Cu not found")
InPot = PolyInside(PotPoly, Gx, Gy)
# Distance-to-pot-boundary test: a cell is "deep" if a disc of radius R around it is inside the pot
def ErodedPot(R):
    Out = InPot.copy()
    K = int(math.ceil(R / Res))
    Pad = np.pad(InPot, K, constant_values=False)
    for Dj in range(-K, K + 1):
        for Di in range(-K, K + 1):
            if math.hypot(Dj, Di) * Res <= R:
                Out &= Pad[K + Dj:K + Dj + Ny, K + Di:K + Di + Nx]
    return Out


HvZoneOk = ErodedPot(PotMargin + HvWidth / 2)
HvViaOk = ErodedPot(PotMargin + ViaD / 2)

# Static geometry: pads, keepouts, edges
Pads = []
for Fp in Board.GetFootprints():
    for Pad in Fp.Pads():
        S = Pad.GetSize(pcbnew.F_Cu)
        Sx, Sy = Mm(S.x), Mm(S.y)
        Lids = [L for L, Lid in enumerate(LayerIds) if Pad.IsOnLayer(Lid)]
        Drill = Mm(max(Pad.GetDrillSize().x, Pad.GetDrillSize().y)) if Pad.HasHole() else 0.0
        Pads.append({"name": Fp.GetReference() + "." + Pad.GetNumber(), "net": Pad.GetNetname(), "x": Mm(Pad.GetPosition().x),
                     "y": Mm(Pad.GetPosition().y), "sx": Sx, "sy": Sy, "rot": Pad.GetOrientationDegrees(), "layers": Lids,
                     "pth": Pad.HasHole(), "drill": Drill, "clr": ClrOf(Pad), "hv": IsHvName(ClassNames(Pad))})
KeepoutPolys = []
for Z in Board.Zones():
    if Z.GetIsRuleArea():
        Ol = Z.Outline().Outline(0)
        Poly = [(Mm(Ol.CPoint(I).x), Mm(Ol.CPoint(I).y)) for I in range(Ol.PointCount())]
        for Lid in Z.GetLayerSet().Seq():
            if Board.GetLayerName(Lid) in Layers:
                KeepoutPolys.append((Layers.index(Board.GetLayerName(Lid)), Poly))
InnerBlocked = np.zeros((4, Ny, Nx), dtype=bool)
for L, Poly in KeepoutPolys:
    InnerBlocked[L] |= PolyInside(Poly, Gx, Gy)

Routed = []   # (net, layer, ax, ay, bx, by, width, clr)
RoutedVias = []  # (net, x, y, clr)


def PadDist(P, GX, GY):
    A = math.radians(P["rot"])
    Lx = (GX - P["x"]) * math.cos(A) - (GY - P["y"]) * math.sin(A)
    Ly = (GX - P["x"]) * math.sin(A) + (GY - P["y"]) * math.cos(A)
    Qx = np.maximum(np.abs(Lx) - P["sx"] / 2, 0)
    Qy = np.maximum(np.abs(Ly) - P["sy"] / 2, 0)
    return np.hypot(Qx, Qy)
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

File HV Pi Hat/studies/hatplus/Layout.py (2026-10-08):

# Layout.py - candidate placement for the HAT+ outline study (board coordinates, mm).
# Footprint origin and rotation follow KiCad: rotation -90 maps local (x, y) to board (X - y, Y + x).

# HAT+ outline: 65 x 56.5 mm, left/top edges where rev A had them, 3 mm corners
Outline = (117.5, 86.0, 182.5, 142.5, 3.0)

# Pot (ADR-0003 interim): 3 mm beyond HV copper; notch radius around the H4 screw
PotMargin = 3.0
H4Notch = (179.0, 138.5, 3.5)

# Soldered HV lead pads (replace the J3/J4 screw terminals)
LeadPad = 2.6
LeadDrill = 1.3
LeadRefs = ("J3", "J4")
Leads = [
    ("J3", "HV_Leads_CH1", [("1", "GND", (162.0, 139.2)), ("2", "/HV_CH1", (178.2, 123.2))]),
    ("J4", "HV_Leads_CH2", [("1", "GND", (168.5, 139.2)), ("2", "/HV_CH2", (178.2, 129.0))]),
]

Place = {
    # Mechanical: standard HAT+ hole pattern and header (unchanged from rev A)
    "H1": (179.0, 89.5, 0), "H2": (121.0, 89.5, 0), "H3": (121.0, 138.5, 0), "H4": (179.0, 138.5, 0),
    "GPIO1": (125.875, 90.775, 90),
    # HV module: courtyard x 160.0..182.2, y 96.5..118.7; LV pins on the top row, HV pin 8 bottom-left
    "U1": (160.3, 96.8, -90),
    # Opto column: LED pins face left (x 147.05), HV pins face right (x 154.0)
    "OR1": (144.0, 95.8, -90),   # CH1 charge: pin3 HV_RAIL, pin4 HV_CH1
    "OR2": (144.0, 107.3, -90),  # CH2 charge: pin3 HV_RAIL, pin4 HV_CH2
    "OR3": (144.0, 118.8, -90),  # CH1 discharge: pin3 HV_CH1_DIS, pin4 GND
    "OR4": (144.0, 130.3, -90),  # CH2 discharge: pin3 HV_CH2_DIS, pin4 GND
    # HV resistors under U1, rotated 180 so pad1 (HV_CHx) is on the right
    "R1": (165.5, 121.0, 180),   # R_dis CH1: HV_CH1 / HV_CH1_DIS
    "R25": (165.5, 125.3, 180),  # R_safety CH1: HV_CH1 / GND
    "R26": (165.5, 129.6, 180),  # R_safety CH2: HV_CH2 / GND
    "R2": (165.5, 133.9, 180),   # R_dis CH2: HV_CH2 / HV_CH2_DIS
    # Ferrite next to U1 pin 1 (VIN); the +5V bulk caps sit at the power entry by header pins 2/4
    # (ADR-0001: bulk stays on +5V, before the ferrite)
    "FB1": (177.0, 94.6, 0),
    "C2": (121.0, 106.0, 90), "C3": (121.0, 110.0, 90), "C4": (121.0, 113.2, 90),
    # PGM stage, top-left
    "U2": (125.0, 97.5, 0), "R9": (128.5, 97.5, 90), "R10": (128.5, 100.8, 90), "C5": (128.0, 94.4, 0),
    "R7": (120.5, 98.0, 90), "R8": (120.5, 101.6, 90), "C1": (123.8, 101.4, 0),
}


def Cluster(Oy, Q, Rled, Rgate, Rpd, Rind=None, Led=None):
    # One opto driver, aligned with the opto whose origin y is Oy (LED+ at Oy+0.635, LED- at Oy+9.525)
    Place[Q] = (139.0, Oy + 9.5, 0)          # drain (pin 3) at x 141.54 faces the opto LED- pin
    Place[Rled] = (141.0, Oy + 1.2, 0)       # +5V to LED+
    Place[Rgate] = (134.5, Oy + 8.2, 0)      # GPIO to gate
    Place[Rpd] = (134.5, Oy + 10.5, 0)       # gate pulldown
    if Rind:
        Place[Led] = (136.0, Oy + 1.2, 0)    # indicator LED, anode on +5V
        Place[Rind] = (136.0, Oy + 4.0, 0)   # indicator resistor to the drain


Cluster(95.8, "Q3", "R6", "R17", "R19", "R11", "D1")    # OR1, GPIO_5
Cluster(107.3, "Q1", "R14", "R18", "R20", "R15", "D2")  # OR2, GPIO_26
Cluster(118.8, "Q2", "R21", "R16", "R13")               # OR3, GPIO_6
Cluster(130.3, "Q4", "R22", "R23", "R24")               # OR4, GPIO_16

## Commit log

2025-12-08 Enhance README description for safety clarification
    Expanded description to include safety information regarding high voltage equipment.
2026-06-07 Foundation, HV design review, and cross-agent handoff docs
    Self-contained libraries (HV_Pi_Hat.pretty + HV_Electronics/MHR0317 symbols) with relinked lib tables; HV spacing enforced via 'HV Pi Hat.kicad_dru' (4mm clearance/creepage/edge on HV nets); R1/R2 bleeders corrected to 100M; datasheets/ added + index; design review (REVIEW_FINDINGS) + corrected active charge/discharge design (CONTROL_DESIGN); schematic control rework started (op-amp PGM stage, ILIMIT tie, decoupling); docs reorganized under docs/ with a short CLAUDE.md index; stop tracking regenerable render/drc artifacts; ignore editor/backup cruft.
    [HV Pi Hat.kicad_sch]
2026-07-20 Decision A1: HV Pi Hat autonomous build + HV/LV route pass
    Schematic finalized to match CONTROL_DESIGN (netlist 30/30, ERC 0); PCB regenerated, placed, HV/LV lane-separated; HV routed on outer layers with inner-layer voids + GND guard pours; custom JLCPCB th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
    [BOM.csv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]
2026-10-08 Route PGM, reconnect op-amp ground, set JLC 7628D stackup
    - Route /GPIO_12_Boost (op-amp out U2.1, feedback R9.2, SMHV0550 PGM
    U1.3). It was unrouted, so the board had no HV setpoint path. The
    route stays on the LV side and enters the module along its LV pin
    column, 2 mm or more from all HV copper.
    - Add a GND stitching via for the F.Cu pour island holding U2.2 (op-amp
    GND) and R8.1 (100 k PGM pulldown). The island was cut off from GND,
    so the op-amp had no return and the PGM-low-at-boot fail-safe did not
    work.
    - Remove dangling and duplicate LV stub segments; solid zone connection
    on the Q1/Q3 GND pads (starved thermals).
    - Stackup: JLCPCB JLC04201H-7628D (0.864 mm outer prepr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
    [BOM.csv, HV Pi Hat.kicad_pcb]
2026-10-08 Remove stale fab outputs and in-repo session state
    - Delete the root-level Gerbers, drill files, HV Pi Hat.zip and .7z:
    a fab-ready set of the December 2025 design, which had the bugs in
    docs/REVIEW_FINDINGS.md (floating ILIMIT, opto resistors too large).
    - Delete fab/preliminary_DO_NOT_FAB/: outputs of an unroutable June
    intermediate whose README no longer matched the board.
    - Add fab/README.md: no fab outputs until ADR-0003 is accepted, an EE
    has reviewed the board, and the order names the ADR-0002 stackup.
    - Delete docs/STATUS.md and docs/EESCHEMA_TODO.md (session state and a
    finished checklist) and the intermediate A1_outer_routed.png render.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
    [HV Pi Hat-B_Adhesive.gbr, HV Pi Hat-B_Courtyard.gbr, HV Pi Hat-B_Cu.gbr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]
2026-10-08 Move decisions to ADRs; record spacing basis and footprint target
    - docs/adr/0001: the old DECISIONS.md tables, with a status per row.
    Fixes the connector contradiction (DECISIONS said SHV-R open; the
    board has a 10.16 mm screw terminal).
    - docs/adr/0002: HV on outer layers, inner voids, JLC 7628D stackup,
    with measured through-board distances (1.91 mm minimum, about
    2.5 kV/mm at 5 kV).
    - docs/adr/0003 (Proposed): the 2 mm spacing has no basis. IEC 60664-1
    Table F.5 gives 20 mm creepage at 5 kV (PD1) and Table F.8 5.7 mm
    clearance; rev A fails those by 354 violations. Recommends
    encapsulating the HV zone (IEC 60664-3 type 2) and qualifying by test.
    - docs/adr/0004: target the s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
2026-10-08 ADR-0003: accept potting the HV zone; interim layout rules
    Anatol chose option 2: encapsulate the HV zone (IEC 60664-3 type 2)
    and qualify by test. The ADR now lists the prerequisites before fab
    (Table 1 spacings, compound, qualification test, reviewing EE) and the
    interim rules for layout work: all HV copper inside a two-face pot,
    2 mm inside it, a 3 mm pot margin, and HV leaving only as soldered
    leads, which retires the J3/J4 screw terminals.
2026-10-08 HAT+ placement study: full route in 65 x 56.5 mm with a potted HV zone
    Issue #4. Places the rev A circuit in the standard HAT+ outline under
    the ADR-0003 interim rules and routes it with a scripted grid router:
    - J3/J4 become soldered-lead pads; U1 turned so its LV pins face the
    header; opto column; HV resistors under U1; driver clusters aligned
    with their optos; +5V bulk caps moved to the power entry.
    - 2 mm run: kicad-cli DRC 0 errors, 0 unconnected, 0 HV vias, HV copper
    3.00 mm or more inside the pot, through-board minimum 2.08 mm.
    - 3 mm run of the same placement: also 0 errors and 0 unconnected.
    - tools/PotMargin.py checks the 3 mm pot margin.
    - ADR-0004 records the feasibility r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
    [hatplus.kicad_pcb]
2026-10-08 Rev B: HAT+ outline board with soldered HV leads and a potted HV zone
    Issue #6. Promotes the placement study (#4) to the main board:
    - Schematic: J3/J4 footprint -> HV_Footprints:HV_LeadPair_P6.00mm
    (pad 1 return, pad 2 HV, 6.0 mm pitch). Netlist connectivity checked
    identical before/after (66 nets, 146 pins); ERC 0 errors.
    - New footprint generated by tools/MakeLeadPair.py.
    - Board: 65 x 56.5 mm HAT+ outline, study placement with J3 at the right
    edge and J4 along the bottom, pot outline + inner voids, routed by
    tools/revb/AutoRoute.py with LV kept out of the pot except over U1's
    LV pin row, GND pours on F/B.
    - DRC: 0 unconnected, 0 clearance/creepage/edge errors at the 2 mm
    int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
    [BOM.csv, HV Pi Hat.kicad_pcb, HV Pi Hat.kicad_sch]
2026-10-08 Rev B: 65 x 56 mm outline, hole lands, Pi 5 underside check (ADR-0005)
    - Outline 65 x 56.0 mm: the legacy HAT drawing gives 56.0 for a
    through-hole GPIO header (56.5 is for SMT, extra 0.5 on the header
    edge); the study's 56.5 had the extra on the wrong edge. J4 moved up
    0.4 mm to keep its 3 mm pot margin.
    - 6.2 mm copper-free land around each mounting hole (HAT drawing).
    - Left-edge strip kept free so a PCIe flex notch stays possible; C2-C4
    moved off it.
    - tools/revb/PiKeepouts.py: Pi 5 parts from the official drawings drawn
    on User.2, with the vertical room at a given standoff. At 16 mm the
    Active Cooler (13.70 mm worst case) collides with the 3 mm bottom pot
    by 0.7 mm; at 20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
    [HV Pi Hat.kicad_pcb]
2026-10-08 ADR-0005: accept 20 mm standoffs
2026-10-08 ADR-0005: 20 mm header proposal (Samtec ESQ-120-14-G-D), fan gap at 20 mm
    The elevated socket sits on the Pi's pins with its tails soldered
    through the HAT on the 20 mm standoffs. Engagement depends on the Pi 5
    pin length above its base, which no official drawing gives: measure
    before ordering. BOM_SOURCED marks the PPTC202 socket as superseded.
2026-10-08 Rev B: opto drive, ID EEPROM, underside socket, NPTH holes, bench plan
    Implements the recommendations from the 2026-10-08 decision list:
    - ADR-0006: opto LED resistors R6/R14/R21/R22 51 Ohm 0603 -> 15 Ohm
    1206. The OPTO-100 datasheet's CTR graph starts at about 40 mA of
    LED current; 51 Ohm gave about 38 mA. 15 Ohm gives about 110 mA.
    - ADR-0007: HAT+ ID EEPROM (CAT24C32 at 0x50, 3.9k ID pull-ups, 1k WP
    pull-up + TP1, 100 nF) added to the schematic by
    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
    [BOM.csv, HV Pi Hat.kicad_pcb, HV Pi Hat.kicad_sch]
2026-10-08 Link bench tests to issue #7; mark the EEPROM edit script one-shot
    [AddIdEeprom.py]
2026-10-08 ADR-0003: not flight-rated; potting compound Sylgard 184, primed
    Anatol's scope cut: the board is a lab instrument, so outgassing no
    longer drives the choice and the space-grade 93-500 (about $1,300 per
    110 g) is set aside. T5 drops thermal vacuum, low-pressure PD and
    outgassing.
2026-10-08 Redraw the ID EEPROM block off the frame line
    AddIdEeprom.py placed U3, R27-R29, TP1 and C6 on the bottom frame
    line with overlapping text, and PWR_FLAG on top of a +3V3 symbol.
    TidyIdEeprom.py moves the block into the empty area under the op-amp,
    ties A0-A2 to one GND with wires, and gives the pull-up and test
    point labels short wire stubs.
    Connectivity unchanged: kicad-cli netlist identical (67 nets, 49
    parts with the same values, footprints and UUIDs); ERC still 0
    errors with the same 8 warnings; DRC unchanged.
    [HV Pi Hat.kicad_sch]
